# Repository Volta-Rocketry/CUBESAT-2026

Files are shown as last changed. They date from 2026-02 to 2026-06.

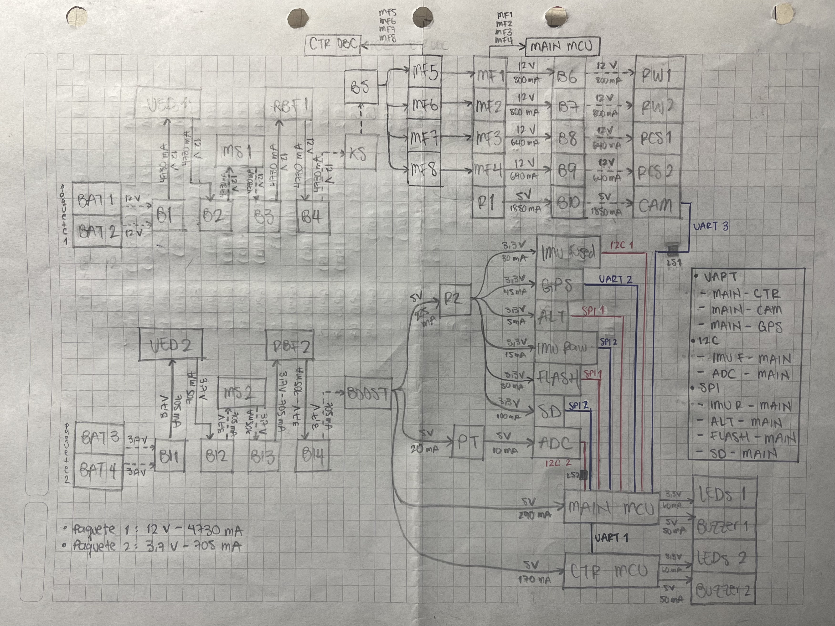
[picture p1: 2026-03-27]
ELS-ELH/Electrical Diagram.jpg

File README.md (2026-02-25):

# CUBESAT-2026
Repo for the CUBESAT - 2026

/ IMAGE OR VIDEO

## Description

Here goes the project description

## Features
Here goes the features and capabilities

## Requirements and Software
Here goes the requirements for developers to run the code

## Usage
Here goes a little guide or referral to usage manual

### IMPORTANT
Here goes important notes

## Authors and Acknowledgments
Here goes the authors and acknowledgments

## License
Here goes the license information

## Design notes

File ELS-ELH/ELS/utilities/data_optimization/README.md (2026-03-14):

## Data Strategy Analysis 
This utility simulates data throughput for a 250s mission profile at 100Hz, comparing Bitmask vs. ID-tag structures to optimize Flash saving efficiency.
## Validation and Reproducibility Steps
1. **Mission Profile:** The script uses a 250s mission profile at 100Hz.
2. **Input Verification:** The sensors used for the analysis were taken from the ones mentioned for the main OBC (The frequency was selected based on common ranges for these types of sensors, as there are no commercial references yet).
3. **Execution:** Run `python optimization_model.py`.
4. **Data Verification:** Compare the total byte count in `Data_Optimization_Analysis.xlsx` or the CSV files against the theoretical weights defined in the `dictionary_sensors` and confirm that low-frequency sensors only contribute data every X cycles, as expected in the ID-tag structure.
5. **Expected Output:** The ID-tag structure should demonstrate higher storage efficiency by omitting redundant data from lower-frequency sensors.

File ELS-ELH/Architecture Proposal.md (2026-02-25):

# ELH-ELS (Electronics Hardware and Software) Architecture Proposal

## Battery Packs Concept
In all proposed architectures, the term battery packs refers to two electrically identical sets of batteries, equal in chemistry, capacity, nominal voltage, and performance envelope. These packs are designed to be interchangeable from an electrical standpoint. However, only one pack is actively used at any given time, while the other remains available as a redundant or alternate source.

## General Elements
Across all proposed architectures, a common set of core subsystems is preserved to ensure functional consistency, comparability, and predictable system behavior. These elements are treated as architecture-invariant, meaning their role, and fundamental interaction model remain unchanged regardless of how processing, control, or power management responsibilities are distributed.

The system includes a GPS receiver used for absolute positioning, velocity estimation, and time reference. This provides global navigation data that complements inertial and barometric measurements and serves as a long-term correction source for state estimation algorithms.

Two inertial measurement units are incorporated with distinct roles. The first is an IMU with integrated sensor fusion capabilities, intended to provide a reliable, low-latency estimate of attitude and angular rates with minimal computational overhead. This fused output is primarily used for fast-loop control, initialization, and redundancy. In parallel, a second IMU dedicated exclusively to raw sensor data acquisition is included. This device provides unprocessed accelerometer, gyroscope and magnetometer measurements, enabling custom filtering, advanced state estimation, post-flight analysis, and algorithm validation independent of vendor-provided fusion.

A single barometric pressure sensor is used for altitude estimation and vertical rate computation. Its data complements inertial measurements and is especially relevant for low-frequency altitude tracking and apogee detection. The barometer is shared as a common input across estimation and logging subsystems.

For data persistence, the system integrates non-volatile flash memory to support continuous onboard data logging during flight. This storage is intended for high-reliability recording of critical sensor data, and system states. In addition, a physical SD card slot is included to allow retrieval of detailed flight data after recovery.

Finally, the system incorporates LED indicators and a buzzer to provide immediate visual and audible feedback regarding system states such as power-up, arming status, fault conditions, and mode transitions.

## Architectures
### Option 1 - Dedicated PMC and Dual OBC
This architecture is built around two identical battery packs, routed through a Power Management Controller (PMC) that acts as the sole authority over power supervision and distribution. Although the packs are electrically identical, their usage is differentiated by design: one pack is primarily associated with the actuator power domain, while the other supplies the onboard computers (OBCs). Only one pack per domain is active at a time, with selection and protection handled according to domain criticality.

The PMC, implemented on a dedicated microcontroller, continuously monitors both identical battery packs by measuring voltage, current, and optionally temperature. In addition to pack-level supervision, it monitors the electrical consumption of each actuator channel individually.

For the actuator power domain, the two identical battery packs are routed through PMC-controlled electronic power switches. The PMC firmware explicitly selects which actuator battery pack is connected to the actuator bus at any given time, and can fully disconnect or switch between packs as needed. This allows the PMC to actively choose the power source for the actuators and to isolate a pack in response to excessive current draw, detected faults, degradation, or higher-level system states.

Downstream of the selected actuator pack, each actuator channel is further gated by electronically controlled switches, also commanded by the PMC. This enables per-channel activation, isolation, and load shedding, ensuring that both pack selection and individual actuator enablement are under direct PMC control.

In contrast, the battery pack supplying the onboard computers is governed primarily by hardware supervision rather than firmware logic. Undervoltage, overcurrent, and brown-out protection are implemented using analog hardware supervisors capable of removing or restoring power independently of PMC firmware execution. The PMC passively observes and reports the state of this OBC power rail, but it does not act as the sole decision-maker. This design ensures that OBC power behavior remains deterministic, bounded, and resistant to software failure, even if the PMC firmware becomes compromised.

Above the PMC operate two onboard computers with clearly separated responsibilities.

OBC #1 (Primary Control OBC) is dedicated exclusively to running control algorithms and robust state estimation. Its design philosophy assumes that actuator power channels are available, not something it actively manages. When channels are enabled by the PMC, OBC #1 simply outputs control signals to the actuators. It does not perform power arbitration, logging, communication, or sensor preprocessing. Its operation depends on receiving validated sensor data and system status from OBC #2.

OBC #2 (Secondary / Data and Services OBC) is responsible for all sensor interfacing and data handling. It acquires raw sensor data, processes and conditions it, runs secondary or complementary state estimation algorithms, and stores data for later retrieval. It also handles non-critical system services such as data logging, Bluetooth communication with an external application. OBC #2 acts as a data provider to OBC #1, delivering sensor information and derived state estimates on demand. In this architecture, OBC #2 is also responsible for communication with the PMC, collecting power status, fault flags, and battery telemetry.

This architecture enforces strict separation: the PMC controls power, OBC #1 controls behavior, and OBC #2 manages data and interaction.

### Option 2 - Dual OBC Architecture Without PMC

Architecture 2 removes the dedicated PMC while keeping the two-OBC structure and the concept of identical battery packs. The packs still exist as separate power sources, but they are no longer routed through an intelligent power authority. Instead, battery protection is limited to passive hardware elements such as fuses, current limiters, and voltage regulators.

Without the PMC, no component has authoritative control over power distribution. Battery pack selection is hardware configured, and no actuator channels can be actively enabled or disabled at runtime based on power conditions. Power-related decisions are reduced to monitoring on pack status.

The Primary Control OBC (OBC #1) retains its focused role: running control algorithms and robust state estimation. It continues to assume that actuator power channels are available, and it outputs control signals accordingly. 

The Secondary OBC (OBC #2) monitors battery voltages and currents and continues to handle sensor processing, data storage, logging, and communication (including Bluetooth). It reports battery status and warnings to OBC #1, but it cannot directly isolate faults or remove power from loads. Communication between the two OBCs remains similar to Architecture 1, but without the PMC, fault handling becomes slower, less deterministic, and entirely software-dependent.

Compared to Architecture 1, this design reduces hardware complexity but sacrifices independent power authority and fast fault isolation.

### Option 3 - Single-OBC

Architecture 3 collapses the responsibilities of Architecture 2 into a single onboard computer. The system still uses one or two identical battery packs, but domain separation is minimal, and power protection relies almost entirely on passive hardware and basic software checks.

In this architecture, the single OBC performs control, state estimation, sensor acquisition, and basic battery monitoring within a single firmware context. Sensor data is processed locally, and only essential state estimation algorithms are executed. Non-essential services are removed: Bluetooth communication and higher-level interaction features are not included.

Battery monitoring is simplified to a reduced set of measurements, typically at lower sampling rates. There is no independent supervisory layer, no secondary data-processing unit, and no authoritative power control. Any software fault or overload directly impacts all system functions simultaneously.

This architecture prioritizes minimal hardware, fast development, and simplicity. Relative to Architectures 1 and 2, it offers the least robustness and the weakest fault isolation, but it may be acceptable for early prototypes or low-risk applications.

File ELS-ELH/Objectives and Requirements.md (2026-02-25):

# ELH-ELS (Electronics Hardware and Software) Objectives and Requirements

## Objectives
### General Objective
Develop an electronics platform to support control, power, and payload operations required for 2026 Volta´s Cubesat mission.
### Specific Objectives
1. Provide electrical power availability to enable nominal operation of all primary subsystems.
2. Support attitude determination and control activities during descent.
3. Enable system-level awareness of mission flight phases for operational decision-making.
4. Ensure system operability through defined modes, including startup, nominal operation, contingency, and safe states.
5. Enable reliable data handling, including acquisition, routing, storage, and access for onboard and ground use.
6. Enable verification and validation of system behavior through observable states and testable interfaces.

## Success Criteria
### Objective 1
- The objective is considered successful if all primary subsystems remain powered and operational throughout all defined operational modes without unintended resets or power interruptions.
### Objective 2
- The objective is considered successful if attitude state information is continuously available to the control logic throughout the descent phase without loss of estimation.
### Objective 3
- The objective is considered successful if the system correctly transitions between defined flight phases in a manner consistent with the mission timeline and external events.
- The objective is considered successful if the current flight phase is externally observable and unambiguous at all times.
### Objective 4
- The objective is considered successful if the system can enter, operate within, and exit all defined operational modes without manual intervention.
- The objective is considered successful if the system can transition to a safe or contingency mode in response to anomalous conditions.
### Objective 5
- The objective is considered successful if mission-critical data is correctly acquired, routed, and made available to onboard consumers when required.
- The objective is considered successful if stored data remains accessible and uncorrupted across operational modes and power cycles.
- The objective is considered successful if relevant data can be accessed at ground after operation
### Objective 6
- The objective is considered successful if system states, transitions, and key behaviors are externally observable through defined interfaces.
- The objective is considered successful if system behavior can be verified through repeatable tests conducted in representative operational conditions.
- The objective is considered successful if test results can be traced to specific objectives and system behaviors.

## System Requirements
- The system shall detect and record power-related anomalies that affect subsystem operation..
- The system shall provide attitude state information required for control functions during the descent phase.
- The system shall support execution of attitude control actions during descent.
- The system shall detect and report loss or degradation of attitude information.
- The system shall maintain an internal representation of the current mission flight phase.
- The system shall transition between defined flight phases based on mission events or conditions.
- The system shall expose the current flight phase as an externally observable state.
- The system shall support startup, nominal, contingency, and safe operational modes.
- The system shall transition between operational modes without manual intervention.
- The system shall maintain basic operational functionality in safe mode.
- The system shall maintain basic operational functionality in safe mode.
- The system shall store mission-critical data for later access.
- The system shall preserve data integrity across operational modes and power cycles.
- The system shall support monitoring of key system behaviors during operation.

## External and Imposed Requirements
- The system shall not include LIPO batteries
- The system shall provide data from the IMU and the Altimeter to the camera subsystem on demand
- The system shall provide functionality to two electrovalves operating at 12V with an aproximate power consumption of 7.6 W.
- The system shall provide functionality to one analog pressure transductor operating at 5V

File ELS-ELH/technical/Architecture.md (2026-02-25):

NOTE: It is missing to add a pressure sensor from the RCS system

# ELH-ELS (Electronics Hardware and Software) Architecture

## Description
The system is based on two electrically identical battery packs providing full energy redundancy, with a dedicated Power Management Controller (PMC) acting as the sole authority for power supervision and distribution, where one pack at a time is selected per domain while the other remains isolated as a hot spare; the PMC continuously monitors voltage, current and faults, actively selects which pack powers the actuator bus, and individually enables, disables, or isolates each actuator channel through electronic switches, while the power rail feeding the onboard computers is protected by independent hardware supervisors (undervoltage, overcurrent and brown-out) that guarantee deterministic behavior even in the presence of PMC firmware failures, with the PMC only monitoring this rail; above this power layer operate two onboard computers with strictly separated roles, where the MAIN OBC performs all system-level functions including sensor acquisition (GPS, fused IMU, raw IMU and barometer), state estimation, data logging to flash and SD, communications, mode management, fault handling and PMC supervision, and distributes validated state information, while the CTR OBC is dedicated exclusively to real-time control and flight dynamics, generating actuator commands based on the received state without handling power, logging or communications, resulting in a modular, fault-tolerant and safety-oriented architecture that cleanly separates electrical authority, system intelligence and control execution.

## Pin and Interface Budget
### PMC
| TYPE | ITEM | PINS | COMMENTS |
|---|---|---|---|
| OUTPUT | Pack selector | 1 | For battery selection |
| OUTPUT | Power Control CH1 (RW motor 1) | 1 | Requirement by RW|
| OUTPUT | Power Control CH2 (RW motor 2) | 1 | Requirement by RW|
| OUTPUT | Power Control CH3 (RCS Valve 1) | 1 |Requirement by RCS|
| OUTPUT | Power Control CH4 (RCS Valve 2) | 1 |Requirement by RCS|
| OUTPUT | Power Control CH5 (CAM) | 1 |Requirement by Camera Control|
| OUTPUT | Power Control CH6 (SOL) | 1 |Requirement by Solar Panel Array|
| COM | UART1 TX (MAIN OBC) | 1 | For communication with main OBC|
| COM | UART1 RX (MAIN OBC) | 1 |For communication with main OBC |
| COM | SDA I2C1 | 1 |I2C1 bus definition |
| COM | SCL I2C1 | 1 |I2C1 bus definition |
| SENSOR | CH1 Power Monitor IC | 0 | Connected to I2C1 |
| SENSOR | CH2 Power Monitor IC | 0 | Connected to I2C1 |
| SENSOR | CH3 Power Monitor IC | 0 | Connected to I2C1 |
| SENSOR | CH4 Power Monitor IC | 0 | Connected to I2C1 |
| SENSOR | CH5 Power Monitor IC | 0 | Connected to I2C1 |
| SENSOR | CH6 Power Monitor IC | 0 | Connected to I2C1 |
| SENSOR | Pack 1 Power Monitor IC | 0 | Connected to I2C1 |
| SENSOR | Pack 2 Power Monitor IC | 0 | Connected to I2C1 |
| OUTPUT | Buzzer | 1 | PWM |
| OUTPUT | LEDs | 3 | PWM |

### MAIN OBC
| TYPE | ITEM | PINS | COMMENTS |
|---|---|---|---|
| COM | UART1 TX (PMC) | 1 | For communication with PMC |
| COM | UART1 RX (PMC) | 1 | For communication with PMC |
| COM | UART2 TX (CTR OBC) | 1 | For communication with Control OBC |
| COM | UART2 RX (CTR OBC) | 1 | For communication with Control OBC |
| COM | UART3 TX (CAM) | 1 | For communication with Cameras Module |
| COM | UART3 RX (CAM) | 1 | For communication with Cameras Module |
| COM | UART4 TX (GPS) | 1 | For GPS module connection |
| COM | UART4 RX (GPS) | 1 | For GPS module connection |
| COM | UART5 TX (BT) | 1 | For BT module coneection |
| COM | UART5 RX (BT) | 1 | For BT module coneection |
| COM | SDA I2C1 | 1 | I2C1 bus definition |
| COM | SCL I2C1 | 1 | I2C1 bus definition |
| COM | SDA I2C2 | 1 | I2C2 bus definition |
| COM | SCL I2C2 | 1 | I2C2 bus definition |
| COM | SCK SPI1 | 1 | SPI1 bus definition|
| COM | MOSI SPI1 | 1 | SPI1 bus definition |
| COM | MISO SPI1 | 1 | SPI1 bus definition |
| COM | SCK SPI2 | 1 |SPI2 bus definition |
| COM | MOSI SPI2 | 1 |SPI2 bus definition |
| COM | MISO SPI2 | 1 | SPI2 bus definition|
| SENSOR | IMU 9DOF Fused | 0 | Connected to I2C1 |
| SENSOR | IMU 9DOF Raw | 0 | Connected to I2C2 |
| SENSOR | Altimeter | 0 | Connected to I2C1 |
| SENSOR | GPS | 0 | Connected to UART5 |
| SENSOR | Flash | 1 | Connected to SPI1 |
| SENSOR | SD Card | 1 | Connected to SPI2 |
| COM | Bluetooth Capability | 0 | Connected to UART |
| OUTPUT | Buzzer | 1 | Connected to PWM |
| OUTPUT | LEDs | 3 | Connected to PWM |
| OUTPUT | SOL Control Channel | 1 | |

### CTR OBC
| TYPE | ITEM | PINS | COMMENTS |
|---|---|---|---|
| COM | UART1 TX (MAIN OBC) | 1 | |
| COM | UART1 RX (MAIN OBC) | 1 | |
| OUTPUT | Control CH1 (RW motor 1) | 1 | PWM |
| OUTPUT | Control CH2 (RW motor 2) | 1 | PWM |
| OUTPUT | Control CH3 (RCS Valve 1) | 1 | PWM |
| OUTPUT | Control CH4 (RCS Valve 2) | 1 | PWM |
| OUTPUT | Control CH5 (RCS Valve 3) | 1 | PWM |
| OUTPUT | Control CH6 (RCS Valve 4) | 1 | PWM |
| OUTPUT | Buzzer | 1 | PWM |
| OUTPUT | LEDs | 3 | PWM |

### Summary
| MCU | UART | I2C | SPI | PWM  | Total Pins |
|---|---|-----|-----|---|---|
| PMC | 1 | 1 | 0 | 4 | 15 |
| MAIN OBC | 5 | 2 | 2 | 4 | 27 |
| CTR OBC  | 1 | 0 | 0 | 10 | 12 | 
---
*NOTE 1:* Main OBC shall include bluethoot capabilities \
*NOTE 2:* Control OBC shall be a control type MCU \
*NOTE 3:* Main OBC can use RTOS

## Power Budget
### PMC
| ITEM | Operating Voltage (V) | Operating Consumption (mA) | Total Power Consumption (W) | Expected Operating Time (s) | Time Justification | Total Energy (Wh) |
| --- | ---: | ---: | ---: | ---: | --- | ---: |
| MCU | 3.3 | 18 | 0.060 | 250 | Always ON (PAD, ascent, mission) | 0.00417 |
| Pack selector | 5.0 | 20 | 0.10 | 250 | Continuous EPS supervision | 0.00694 |
| Power Control CH1 (RW motor 1)  | 12.0 | 800 | 9.6 | 223 | Continuous roll stabilization post-ejection | 0.595 |
| Power Control CH2 (RW motor 2)  | 12.0 | 800 | 9.6 | 223 | Continuous roll stabilization post-ejection | 0.595 |
| Power Control CH3 (RCS Valve 1) | 12.0 | 640 | 7.7 | 22 | Intermittent roll corrections (~10% duty) | 0.0470 |
| Power Control CH4 (RCS Valve 2) | 12.0 | 640 | 7.7 | 22 | Intermittent roll corrections (~10% duty) | 0.0470 |
| Power Control CH5 (CAM) | 5.0 | 1850 | 9.25 | 250 | Explicit requirement: full mission | 0.642 |
| Power Control CH6 (SOL) | 5.0 | 200 | 1.0 | 5 | Single-shot nichrome heating | 0.00139 |
| CH1 Power Monitor IC | 3.3 | 5 | 0.017 | 250 | Continuous power monitoring | 0.00118 |
| CH2 Power Monitor IC | 3.3 | 5 | 0.017 | 250 | Continuous power monitoring | 0.00118 |
| CH3 Power Monitor IC | 3.3 | 5 | 0.017 | 250 | Continuous power monitoring | 0.00118 |
| CH4 Power Monitor IC | 3.3 | 5 | 0.017 | 250 | Continuous power monitoring | 0.00118 |
| CH5 Power Monitor IC | 3.3 | 5 | 0.017 | 250 | Continuous power monitoring | 0.00118 |
| CH6 Power Monitor IC | 3.3 | 5 | 0.017 | 250 | Continuous power monitoring | 0.00118 |
| Pack 1 Power Monitor IC | 3.3 | 5 | 0.017 | 250 | Continuous pack monitoring | 0.00118 |
| Pack 2 Power Monitor IC | 3.3 | 5 | 0.017 | 250 | Continuous pack monitoring | 0.00118 |
| Buzzer | 5.0 | 50 | 0.25 | 20 | Distributed status beeps | 0.00139 |
| LEDs (3×) | 3.3 | 60 | 0.20 | 250 | Continuous status indication | 0.0139 |

### Main OBC
| ITEM | Operating Voltage (V) | Operating Consumption (mA) | Total Power Consumption (W) | Expected Operating Time (s) | Time Justification | Total Energy (Wh) |
| --- | ---: | ---: | ---: | ---: | --- | ---: |
| MCU | 3.3 | 180 | 0.60 | 250 | Always ON | 0.0417 |
| IMU 9DOF Fused | 3.3 | 30 | 0.10 | 223 | Only useful post-ejection | 0.00619 |
| IMU 9DOF Raw | 3.3 | 15 | 0.05 | 250 | Launch detection + backup | 0.00347 |
| Altimeter | 3.3 | 5 | 0.017 | 250 | Launch, apogee, descent awareness | 0.00118 |
| GPS | 3.3 | 45 | 0.15 | 223 | Post-ejection navigation | 0.00929 |
| Flash | 3.3 | 30 | 0.10 | 250 | Primary flight data logger | 0.00694 |
| SD Card (active) | 3.3 | 100 | 0.33 | 10 | Landing-only data dump | 0.00092 |
| Bluetooth Capability | 3.3 | 40 | 0.13 | 0 | Disabled in flight | 0.00000 |
| Buzzer | 5.0 | 50 | 0.25 | 20 | Distributed status beeps | 0.00139 |
| LEDs (3×) | 3.3 | 60 | 0.20 | 250 | Continuous status indication | 0.0139 |

### CTR OBC
| ITEM | Operating Voltage (V) | Operating Consumption (mA) | Total Power Consumption (W) | Expected Operating Time (s) | Time Justification | Total Energy (Wh) |
| --- | ---: | ---: | ---: | ---: | --- | ---: |
| MCU | 3.3 | 80 | 0.26 | 223 | Control active only post-ejection | 0.0161 |
| Buzzer | 5.0 | 50 | 0.25 | 20 | Distributed status beeps | 0.00139 |
| LEDs (3×) | 3.3 | 60 | 0.20 | 223 | Active during CubeSat mission | 0.0124 |

### Raw Summary
| CATEGORY | INCLUDED ELEMENTS | Total Energy (Wh) | COMMENT |
| --- | --- | ---: | --- |
| Actuation & Payload Channels | RW motors (×2), RCS valves (×2), Camera channel, SOL nichrome channel | ≈ 1.93 Wh | Dominant energy driver; camera + RW are primary contributors |
| Computation, Sensors & ICs | All MCUs (PMC, Main OBC, CTR OBC), IMUs, GPS, Altimeter, Flash, SD , Power Monitor ICs, LEDs, Buzzers | ≈ 0.15 Wh | Control, sensing, monitoring, and housekeeping |

### Final decision
The total energy budget is divided into two independent battery domains with margins applied according to the dominant risks of each domain. The first domain, corresponding to actuation and payload channels (reaction wheels, RCS valves, camera channel, and the single-shot nichrome deployment channel), is active only during the mission phase after CubeSat ejection and is therefore dominated by short-duration, high-power operation. For this domain, the raw mission energy of approximately 1.93 Wh is increased by an allowance for EPS conduction and switching losses (≈10%), followed by a DC/DC conversion and wiring efficiency margin of 15%, and a system-level design margin of 30% to cover uncertainty in duty cycles and actuator usage. These combined margins result in a required battery capacity of approximately 3.0 Wh for the actuation and payload battery.

The second domain supplies all computation, sensing, and housekeeping functions, including all MCUs, sensors, memory devices, power monitor ICs, LEDs, and buzzers, and is dominated by long-duration low-power operation during the PAD phase. For this domain, the base energy consists of approximately 0.15 Wh during the mission plus about 1.5 Wh consumed during a three-hour PAD period, with an additional small allowance for EPS quiescent currents and leakage. Margins applied to this domain include a 15% margin for DC/DC conversion and distribution losses, a 20% derating to account for temperature effects and battery aging, and a 30% design margin to cover variability in PAD duration and operational modes. After applying these margins, the resulting required battery capacity for the computation and sensor domain is approximately 3.2 Wh.

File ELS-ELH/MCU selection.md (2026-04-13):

| Features | ESP32-S3 | ESP32-WROOM | ESP32-C3 | ESP32-C6 | ESP32-H2 |
|---|---|---|---|---|---|
| Clock Frequency (MHz) | 240 | 240 | 160 | 160 | 96 |
| SRAM (KB) | 512 | 520 | 400 | 512 | 320 |
| Flash (MB) | 16 | 4 | 4 | 8 | 4 |
| GPIO Quantity | 45 | 34 | 22 | 30 | 28 |
| Pin Restriction | 0 | 4 | 0 | 0 | 0 |
| Analog Output | 0 | 2 | 0 | 0 | 0 |
| Bluetooth | BLE | BLE & Classic | BLE | BLE | BLE |
| Wi-Fi | Yes | Yes | Yes | Yes | No |

The ESP32-WROOM is selected because it meets the requirement of Bluetooth Classic, in addition to BLE, unlike the ESP32-S3, ESP32-C3, ESP32-C6, and ESP32-H2, which only support BLE. 

In terms of performance, the ESP32-WROOM offers a good balance, with a clock frequency of 240 MHz and 520 KB of SRAM. Although the ESP32-S3 stands out for having more Flash memory (16 MB) and more GPIOs, it does not meet the Bluetooth Classic requirement. 

Also, the C3, C6, and H2 models have lower processing capabilities and also lack Bluetooth Classic, so they are discarded. 

Therefore, the ESP32-WROOM is the most suitable choice for the project, providing the necessary Bluetooth functionality while maintaining a strong performance profile.

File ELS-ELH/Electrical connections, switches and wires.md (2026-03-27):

# Electrical Connections, Switches, and Wires

## Purpose of this Document
This document defines part of the proposed final structure system for the CUBESAT for 2026 IREC competition, focusing on electronic safety equipment.

## Electronics Safety Equipment
A system with three types of switches is proposed for the electronic structure of the CUBESAT for reasons of safety, versatility, and with the aim of preventing discharges or long system operating times. However, some guidelines should be taken into account.

## Electrical Schematic Diagram 
The diagram is in this same folder in JPG format.

Electrical Schematic Diagram

### Meaning of each abbreviation
| Abbreviation | Meaning | 
| :--- | :--- |
| BAT1 | Battery Pack 1 | 
| BAT2 | Battery Pack 1 | 
| BAT3 | Battery Pack 2 | 
| BAT4 | Battery Pack 2 | 
| UED1 | Unknown Energy Distributor 1 | 
| UED2 | Unknown Energy Distributor 2 | 
| MS1 | Master Switch 1 | 
| MS2 | Master Switch 2 | 
| RBF1 | Remove Before Fly 1 | 
| RBF2 | Remove Before Fly 2 | 
| KS | Kill Switch | 
| BOOST | Booster | 
| R1 | Regulator 1 | 
| R2 | Regulator 2 | 
| CAM | Camera | 
| PT | Pressure Transducer |
| RW(1,2) | Reaction Wheels |
| RCS(1,2) | Electroválvulas |
| LS1 | Level Shifter 1 | 
| LS2 | Level Shifter 2 | 
| MF(1-8) | Mosfets | 
| B(1-14) | Borneras |

### Master Switch
This switch is used as redundancy for the rbf switch. If it were not there, the system's power supply would depend on it (RBF), which is very volatile and would pose many risks. It (MASTER) is used for security functions.

### RBF Switch
This switch consists of a removable pin that is inserted and removed through a hole in the fuselage when the CUBESAT is assembled inside the launch vehicle. The pin is inserted, the master switch is turned on, and then the pin is removed from the RBF to energize the computing and sensor area.

### Kill Switch
These switches are located in the actuator area and allow power to pass only when the CUBESAT is ejected from the launch vehicle.

### MOSFETS
These are electronic switches located in each actuator, there are two MOSFETs per actuator, both connected in series, for a total of eight. Each “column” has four, and each will be controlled by a different OBC: the main OBC will manage the power supply, and the control OBC will manage the actuators' activation.

## Pin Budget (Preliminar)
### 1. MAIN OBC: ESP32-S3 (DevKitC-1)

| Categoría | Ítem | Pin (GPIO) |
| :--- | :--- | :--- |
| COM | UART1 TX (CTR OBC) | 43 | 
| COM | UART1 RX (CTR OBC) | 44 | 
| COM | UART2 TX (CAM) | 15 | 
| COM | UART2 RX (CAM) | 16 |
| COM | UART3 TX (GPS) | 17 | 
| COM | UART3 RX (GPS) | 18 |
| I2C1 | SDA (IMU Fused) | 4 | 
| I2C1 | SCL (IMU Fused) | 5 | 
| I2C2 | SDA (ADC) | 6 | 
| I2C2 | SCL (ADC) | 7 | 
| SPI1 | SCK (Flash/ALT) | 12 | 
| SPI1 | MOSI (Flash/ALT) | 11 | 
| SPI1 | MISO (Flash/ALT) | 13 |
| CS1 | CS (Flash) | 10 | 
| CS1 | CS (ALT) | 14 | 
| SPI2 | SCK (IMU Raw/SD) | 36 | 
| SPI2 | MOSI (IMU Raw/SD) | 35 | 
| SPI2 | MISO (IMU Raw/SD) | 37 |
| CS2 | CS (IMU Raw) | 47 | 
| CS2 | CS (SD) | 48 | 
| OUTPUT | Buzzer | 2 | 
| OUTPUT | LEDs x3 | 38, 39, 40 | 
| OUTPUT | MOSFET 1 (RW1) | 21 | 
| OUTPUT | MOSFET 2 (RW2) | 41 | 
| OUTPUT | MOSFET 3 (RCS1) | 42 | 
| OUTPUT | MOSFET 4 (RCS2) | 9 | 

### 2. CTR OBC: TEENSY 4.1

| Categoría | Ítem | Pin |
| :--- | :--- | :--- |
| COM | UART1 TX (MAIN OBC) | 1 | 
| COM | UART1 RX (MAIN OBC) | 0 | 
| OUTPUT | Buzzer | 6 | 
| OUTPUT | LEDs x3 | 9, 10, 11 | 
| OUTPUT | MOSFET 5 (RW1) | 2 | 
| OUTPUT | MOSFET 6 (RW2) | 3 | 
| OUTPUT | MOSFET 7 (RCS1) | 4 | 
| OUTPUT | MOSFET 8 (RCS2) | 5 |

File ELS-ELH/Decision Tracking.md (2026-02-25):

# ELH-ELS (Electronics Hardware and Software) Decision Tracking

## Objective and Scope
The purpose of this document is to formally capture, justify, and maintain traceability of all major technical and architectural decisions related to the ELH-ELS (Electronics Hardware and Software) system.

The scope includes, but is not limited to:

- Hardware architecture and component selection
- Firmware and software architecture
- Interfaces, protocols, and data flows
- Safety, redundancy, and fault-handling strategies
- Power, performance, and reliability trade-offs

### Note
All prices are quoted in USD and, unless otherwise specified, electronic component pricing is sourced from the Mouser Electronics website.

## Decisions
### Architecture
Based on team reviews, CubeSat standards, and system-level requirements, Architecture #1 (PMC with dual OBC) has been selected as the baseline.

This architecture provides the highest level of reliability, fault tolerance, and compliance with mission requirements. The use of a Power Management Controller (PMC) combined with dual On-Board Computers (OBCs) enables a modular, redundant, and safety-oriented design, ensuring:

- Robust fault detection, isolation, and recovery (FDIR)
- Controlled power distribution and system-level supervision
- Redundant command and data handling
- Graceful degradation in case of subsystem failure

### Component Selection - Power
#### Load Switches
Three architectures were evaluated for controlling and protecting the CubeSat power distribution rails: (1) discrete MOSFET switches driven directly by the MCU, (2) integrated eFuse / hot-swap power switches, and (3) mechanical relays. A discrete MOSFET approach provides basic on/off capability but requires additional circuitry for inrush control, short-circuit protection, reverse-current blocking, and thermal protection, making it highly layout-dependent and sensitive to EMI and PCB parasitics. Mechanical relays, while simple to control, are unsuitable due to vibration sensitivity, arcing, slow response time, and limited lifetime. Integrated eFuses combine a high-side MOSFET with programmable current limiting, soft-start, short-circuit and thermal protection, reverse-current blocking, and fault reporting in a single device, requiring only minimal external components and a simple MCU interface. This architecture provides the highest level of electrical protection with the lowest implementation complexity and risk, making the eFuse-based solution the most robust and appropriate choice for the CubeSat Power Management Computer.

The devices listed in the following table represent the full spectrum of integrated eFuse solutions available for protected power distribution, spanning from low-power to very high-current applications. These parts were selected for comparison because they share the same architectural model, integrated back-to-back MOSFETs, programmable current limiting, inrush control, reverse-current blocking, thermal protection, and MCU-friendly EN/FLT/PGOOD interfaces, while differing mainly in voltage range, current capability, and $R_{DS_{on}}$. 

Lower-current parts such as the TPS25940 and TPS25946 are well suited for CubeSat subsystem rails, offering sufficient current capacity with lower cost and simpler PCB thermal requirements. Higher-current devices (TPS25983 and TPS25984x) support much larger loads but require larger packages, heavier copper, wider pours, and more thermal management, significantly increasing PCB complexity, mass, and layout risk. 

| Part | Voltage  | Current  | Good For | Price (1/10/25)|
| --- | --- | --- | --- |----|
| **TPS25940** | 2.7–18 V | ~0.6–5 A | Base solution for low-power CubeSat rails | 2.75/2.02/1.85|
| **TPS25946** | 2.7–23 V | ~0.5–6 A | Higher voltage & lower R<sub>ds(on)</sub> | 1.43/1.04/0.95|
| **TPS25983** | 2.7–26 V | ~2–20 A  | Mid-high power rails |3.75/2.84/2.61|
| **TPS25984x** | 4.5–16 V | ~10–55 A | Heavy power distribution |8.21/5.74/5.47|

**NOTE: DECISION FROM THIS OPTION WILL TAKE PLACE AFTER THE POWER REQUIREMNTS PER CHANEL HAVE BEEN RECIEVED**

#### Power Monitor ICs
There are three viable approaches to measure power consumption in a system: (1) measuring voltage and current separately using analog dividers and shunt resistors connected to the MCU ADC, which requires external amplifiers, careful filtering, and calibration; (2) measuring only current with a shunt plus an external current-sense amplifier and then digitizing it with the ADC; or (3) using integrated high-side power monitor ICs such as the INA28x family, which include a precision amplifier, ADC, and digital interface in a single device. 

While the first two options are feasible, they introduce significant analog complexity, noise sensitivity, and calibration burden. In contrast, INA-class power monitors provide accurate high-side current, bus voltage, and power measurements with minimal external components, making them the most robust, scalable, and low-risk solution for multi-rail power telemetry and protection in a flight-critical or high-reliability power system.

The devices listed in the following table were selected for high-side current and voltage monitoring of the CubeSat power rails, balancing accuracy, bus voltage range, and integration features. The INA226 operates over 0–36 V with a 16-bit ADC and ~0.1% accuracy, making it a reliable industry-standard choice for general-purpose telemetry. The INA238 extends the bus voltage range to 0–85 V with improved accuracy (~0.05%) and a radiation-tolerant design, offering heritage suitable for aerospace applications. The MAX34417 supports 0–36 V, 16-bit resolution, and includes built-in alert functionality and filtering, simplifying system monitoring and fault detection. These devices were chosen over older alternatives such as the INA219 because they provide higher precision, true high-side sensing, alerting, and better long-term stability, which are critical for accurate measurement of multiple power rails in a CubeSat environment.

| Part | Bus Voltage | ADC | Accuracy | Addressing | Notes | Price (1/10/25)|
| --- | --- | --- | --- | --- | --- | --|
| **INA226** | 0–36 V | 16-bit | ~0.1% | 16 addr | Industry workhorse | 3.81/2.88/2.65
| **INA238** | 0–85 V | 16-bit | ~0.05% | 16 addr | Radiation-tolerant heritage | 3.17/2.38/2.18
| **MAX34417** | 0–36 V | 16-bit | ~0.1% | 8 addr | Built-in alert + filters | 15.26/11.60/11.12

**NOTE: DECISION FROM THIS OPTION WILL TAKE PLACE AFTER THE POWER REQUIREMNTS PER CHANEL HAVE BEEN RECIEVED**

#### Battery pack switchover alternatives
For providing a single output from two battery packs, three approaches were considered: (1) simple diodes for OR-ing, (2) MCU-controlled MOSFET switches, and (3) ideal-diode OR-ing controllers with external MOSFETs. Simple diodes are electrically safe but introduce significant voltage drop and wasted energy, which reduces usable battery capacity and efficiency. MCU-controlled switches offer apparent flexibility but carry high risk of cross-conduction, brownouts, and failure in case of firmware errors, making them unsuitable for critical power paths. Ideal-diode OR-ing controllers combine automatic source selection, low forward voltage drop, and inherent reverse-current blocking using external MOSFETs, providing seamless switchover without firmware dependency and minimal losses. This architecture achieves the lowest practical complexity while maintaining safety and efficiency, making the ideal-diode OR-ing the most robust and appropriate solution for CubeSat battery pack management.

The ICs listed in the following table were selected as suitable solutions for automatic battery pack switchover based on voltage range, efficiency, and integration features. The LM74700D-Q1 supports a wide voltage range (~3.2–65 V) with very low forward voltage drop, making it ideal for robust, low-loss selection across a broad set of battery chemistries and voltages. The LTC4412 provides automotive-grade ideal-diode control for 2.5–28 V systems, offering proven reliability, low quiescent current, and seamless switchover, suitable for standard CubeSat Li-ion packs. The MAX5079 operates up to 13.2 V and includes built-in ORing logic and status detection, simplifying system monitoring and reducing external components. These devices were chosen over discrete MOSFET logic or passive diodes because they ensure safe, low-loss, and automatic selection without firmware dependency, while minimizing PCB complexity and design risk.

| IC | Best for battery packs up to… | Key benefit | Price (1/10/25)|
| --- | --- | --- | ---|
| **LM74700D-Q1** | ~3.2 – 65 V | Very low loss, wide voltage range | 2.41/1.79/1.64
| **LTC4412** | ~2.5 – 28 V | Automotive-class ideal diode control | 15.23/11.95/11.46
| **MAX5079** | ~2.75 – 13.2 V | Built-in detection and ORing logic | 11.32/8.86/8.73

**NOTE: DECISION FROM THIS OPTION WILL TAKE PLACE AFTER THE POWER REQUIREMNTS PER CHANEL HAVE BEEN RECIEVED**

#### Kill switches

### Component Selection - OBCs
#### PMC - MCU 

#### Main OBC - MCU

#### Main OBC - 9DOF IMU Fused

#### Main OBC - 9DOF IMU Raw

#### Main OBC - Altimeter

#### Main OBC - GPS

#### Main OBC - Flash Module

#### Main OBC - Bluethoot Module

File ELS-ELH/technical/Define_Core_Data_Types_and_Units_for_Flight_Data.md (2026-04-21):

# Objective
In this part, the data and their physical units are defined, enabling consistent information exchange among the participants. This avoids variable discrepancies and interpretation errors, regardless of the hardware. Additionally, all sensors will use the exact units established in this document.
# Data Standards and Physical Units
* **Acceleration:** Meters per second squared ($m/s^2$). Variable: `accel`
  Type: `float`
* **Linear Velocity:** Meters per second ($m/s$). Variable: `linVel`
  Type: `float`
* **Angular Velocity:** Radians per second ($rad/s$). Variable: `angVel` Type: `float`
* **Magnetometer:** microteslas ($\mu T$). Variable: `mag` Type: `float`
* **Pressure:** Pascals ($Pa$). Variable: `pressure` Type: `float`
* **Altitude:** Meters ($m$). Variable: `altitude` Type: `float`
* **Temperature:** Degrees Celsius ($^\circ C$). Variable: `temp` Type: `float`
* **Humidity:** Percentage (%). Variable: `humidity` Type: `float`
* **Time:** Miliseconds ($ms$) since system startup. Variable: `timestamp` Type: `uint32_t`
* **Speed** Meters per second ($m/s$). Variable: `speed` Type: `float`

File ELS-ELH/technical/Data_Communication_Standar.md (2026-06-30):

# Data Communication Standar
---
## General

Before each packet, two separate bytes [0xAA 0x55] (uint8_t) will be sent to identify its arrival.

Each packet will have a designated ID (uint8_t) at the beginning, followed by a set packet length (uint8_t) to confirm its termination, and a CRC (uint16_t) at the end to verify the packet's integrity upon receipt.

The length_of_package variable indicates the payload length (the exact number of bytes containing the data, excluding the Sync bytes, ID, Length byte, and CRC).

All multi-byte variables shall be transmitted in Little-Endian byte order.

---

## ID Package Assignment

* ID_CTR_TP: 0X10
* ID_CAM_TP: 0X11
* ID_FGH_SP: 0X20
* ID_INIT_CMD: 0XF0

---

## Flight Data Packages

* **control_telemetry_package (CTR_TP):** package sent to the control algorithm

    * **Frequency:** 100 Hz
    * **Weight:** 59 Bytes
    * **Content:** 

        | VARIABLE | TYPE | UNIT |
        | :--- | :---: | :--- |
        | 0xAA | uint8_t | N/A |
        | 0x55 | uint8_t | N/A |
        | ID_CTR_TP | uint8_t | N/A |
        | length_of_package | uint8_t | byte |
        | timestamp | uint32_t | ms |
        | altitude | float32 | m |
        | vertical_velocity | float32 | m/s |
        | ax, ay, az | float32 | m/s^2 |
        | gx, gy, gz | float32 | rad/s |
        | qw, qx, qy, qz | float32 | N/A |
        | flight_state | uint8_t | N/A |
        | CRC-16-CCITT | uint16_t | N/A |

* **camera_telemetry_package (CAM_TP):** package sent to the camera algorithm

    * **Frequency:** 100 Hz
    * **Weight:** 34 Bytes
    * **Content:** 

        | VARIABLE | TYPE | UNIT |
        | :--- | :---: | :--- |
        | 0xAA | uint8_t | N/A |
        | 0x55 | uint8_t | N/A |
        | ID_CAM_TP | uint8_t | N/A |
        | length_of_package | uint8_t | byte |
        | timestamp | uint32_t | ms |
        | ax, ay, az | float32 | m/s^2 |
        | gx, gy, gz | float32 | rad/s |
        | CRC-16-CCITT | uint16_t | N/A |

* **flight_state_package (FGH_SP):** package containing flight status

    * **Frequency:** N/A
    * **Weight:** 15 Bytes
    * **Content:** 

        | VARIABLE | TYPE | UNIT |
        | :--- | :---: | :--- |
        | 0xAA | uint8_t | N/A |
        | 0x55 | uint8_t | N/A |
        | ID_FGH_SP | uint8_t | N/A |
        | length_of_package | uint8_t | byte |
        | timestamp | uint32_t | ms |
        | altitude | float32 | m |
        | flight_state | uint8_t | N/A |
        | CRC-16-CCITT | uint16_t | N/A |

---

## Initialize Communications Packages

* **package_init_from_Main:** package sent from main OBC to verify communications, contains the receiver ID

    * **Frequency:** N/A
    * **Weight:** 7 Bytes
    * **Content:** 

        | VARIABLE | TYPE | UNIT |
        | :--- | :---: | :--- |
        | 0xAA | uint8_t | N/A |
        | 0x55 | uint8_t | N/A |
        | ID_INIT_CMD | uint8_t | N/A |
        | length_of_package | uint8_t | byte |
        | ID_CAM_TP / ID_CTR_TP | uint8_t | N/A |
        | CRC-16-CCITT | uint16_t | N/A |

* **package_init_to_Main:** package sent from main OBC to verify communications, contains the transmitter ID

    * **Frequency:** N/A
    * **Weight:** 7 Bytes
    * **Content:** 

        | VARIABLE | TYPE | UNIT |
        | :--- | :---: | :--- |
        | 0xAA | uint8_t | N/A |
        | 0x55 | uint8_t | N/A |
        | ID_INIT_CMD | uint8_t | N/A |
        | length_of_package | uint8_t | byte |
        | ID_CAM_TP / ID_CTR_TP | uint8_t | N/A |
        | CRC-16-CCITT | uint16_t | N/A |

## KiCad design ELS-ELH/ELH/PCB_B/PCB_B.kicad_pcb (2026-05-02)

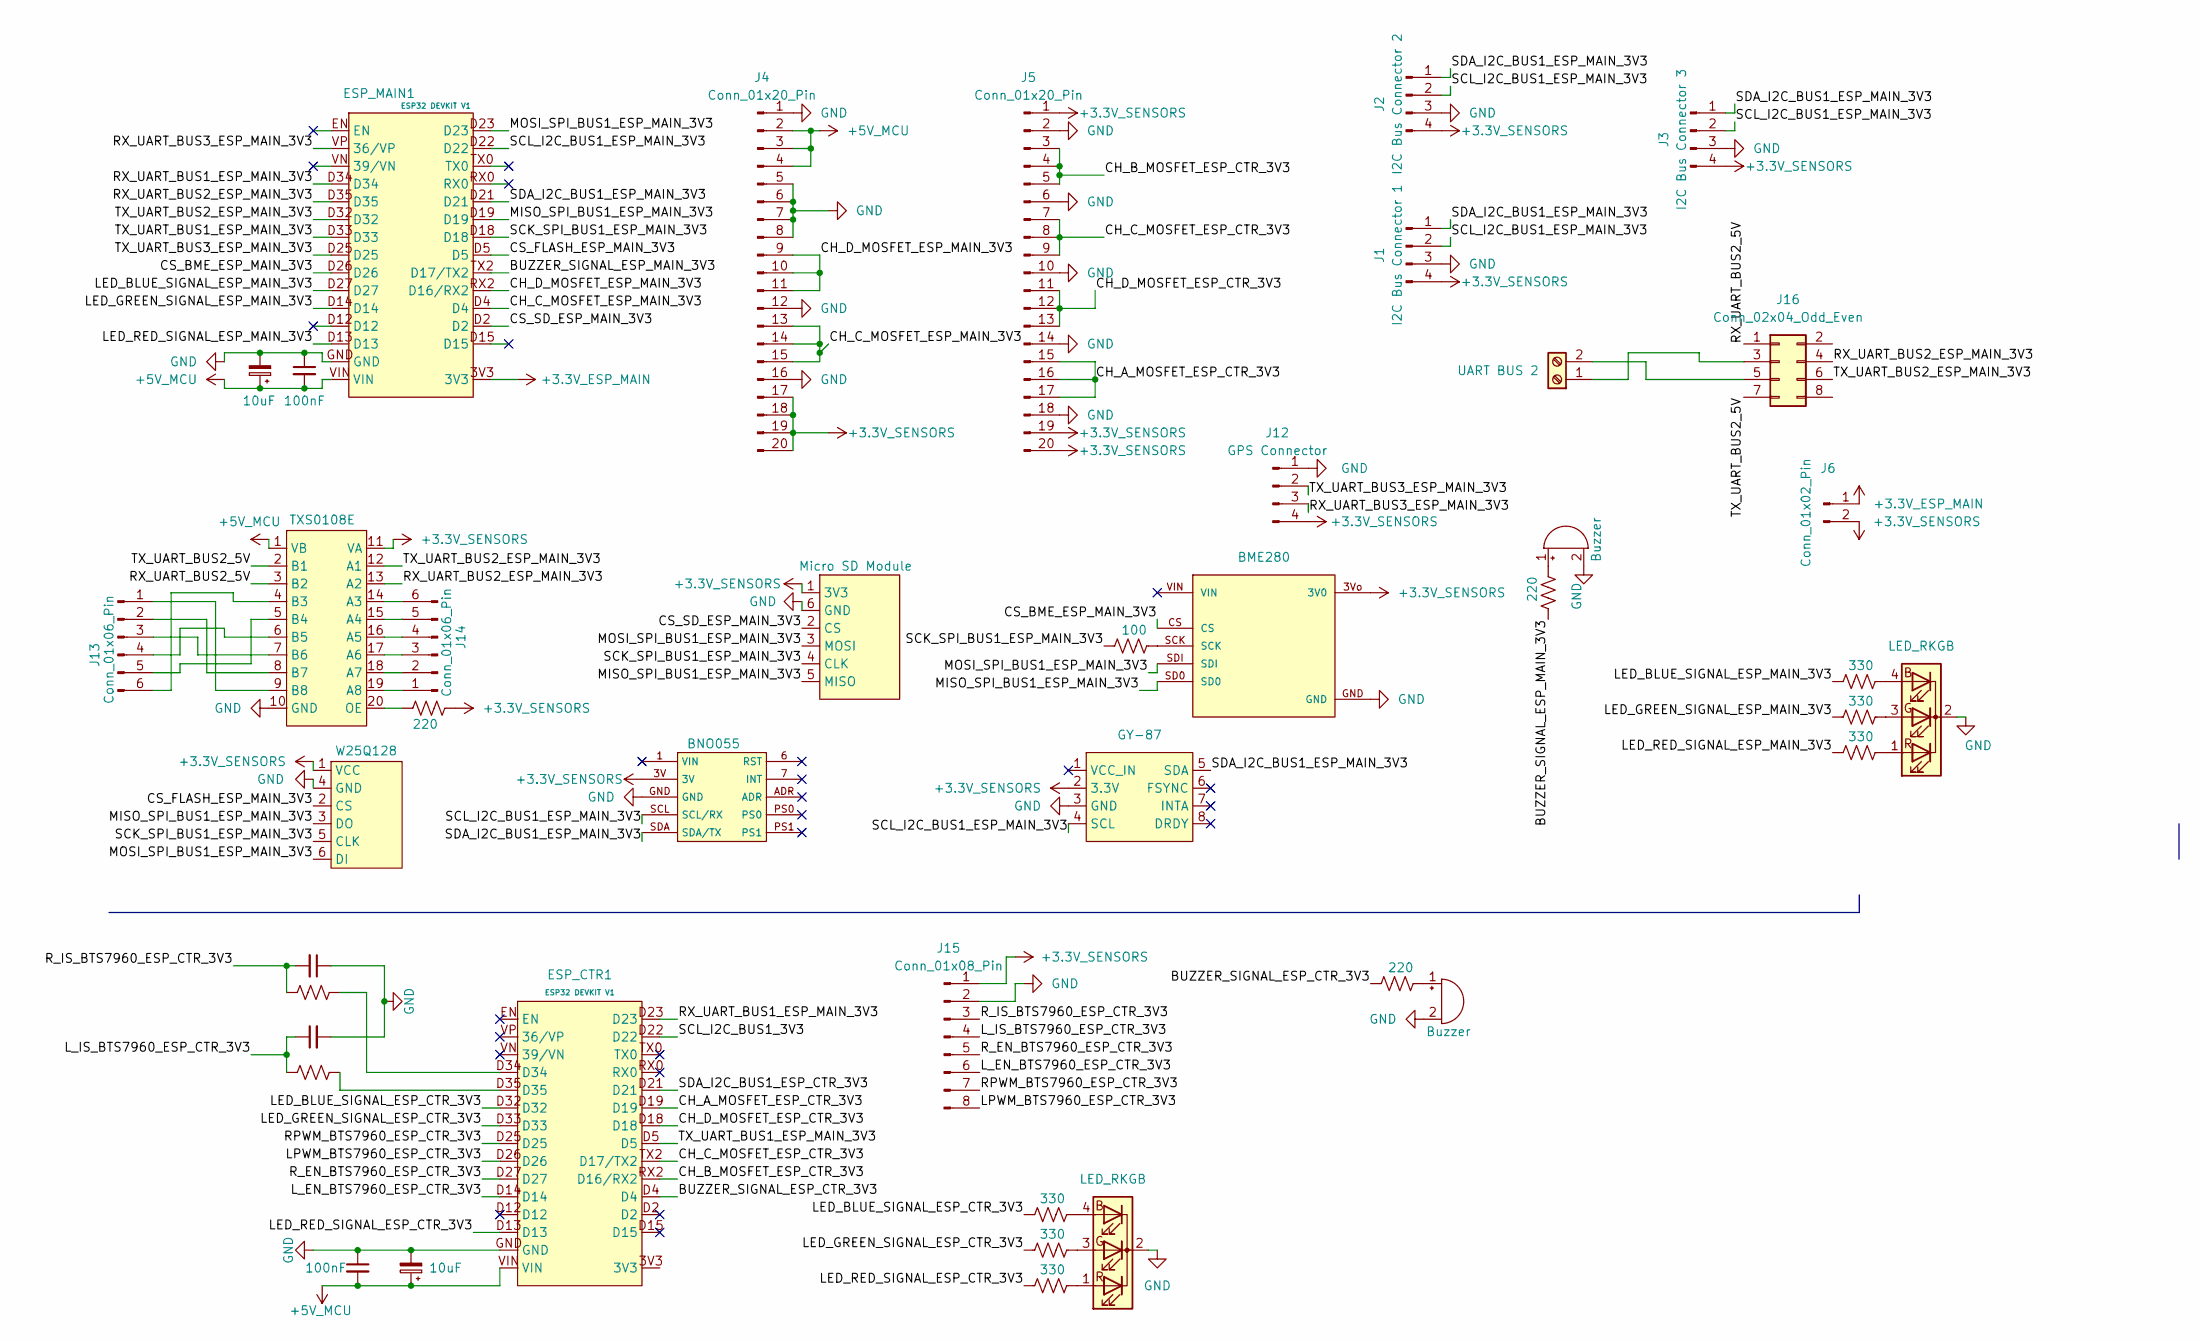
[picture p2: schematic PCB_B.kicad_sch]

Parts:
BME1: BME280
BZ1, BZ2: Buzzer
Bornera1: UART BUS 2
C1, C6: 10uF
C2, C5: 100nF
C3, C4: ???
Converter1: TXS0108E
D1, D2: LED_RKGB
ESP_CTR1: ESP32 DEVKIT V1
ESP_MAIN1: ESP32 DEVKIT V1
IMU1: BNO055
J1: I2C Bus Connector 1
J2: I2C Bus Connector 2
J3: I2C Bus Connector 3
J4, J5: Conn_01x20_Pin
J6: Conn_01x02_Pin; PinHeader_1x02_P2.54mm_Vertical
J12: GPS Connector
J13, J14: Conn_01x06_Pin
J15: Conn_01x08_Pin
J16: Conn_02x04_Odd_Even; PinHeader_2x04_P2.54mm_Vertical
R1, R3, R4, R10, R11, R12: 330
R2, R6, R7: 220
R5: 100
R8, R9: ???
SD_Adapter1: Micro SD Module; MicroSD Module
U1: GY-87
W25QXX1: W25Q128

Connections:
+3.3V_ESP_MAIN: ESP_MAIN1.3V3, J6.1
+3.3V_SENSORS: BME1.3Vo (3V0), Converter1.11 (VA), IMU1.3V, J1.4, J2.4, J3.4, J4.17, J4.18, J4.19, J4.20, J5.1, J5.19, J5.20, J6.2, J12.4, J15.1, R6.1, SD_Adapter1.1 (3V3), U1.2 (3.3V), W25QXX1.1 (VCC)
+5V_MCU: C1.1, C2.2, C5.2, C6.1, Converter1.1 (VB), ESP_CTR1.VIN, ESP_MAIN1.VIN, J4.2, J4.3, J4.4
/BUZZER_SIGNAL_ESP_CTR_3V3: ESP_CTR1.D4, R7.1
/BUZZER_SIGNAL_ESP_MAIN_3V3: ESP_MAIN1.TX2 (D17/TX2), R2.1
/CH_A_MOSFET_ESP_CTR_3V3: ESP_CTR1.D19, J5.15, J5.16, J5.17
/CH_B_MOSFET_ESP_CTR_3V3: ESP_CTR1.RX2 (D16/RX2), J5.3, J5.4, J5.5
/CH_C_MOSFET_ESP_CTR_3V3: ESP_CTR1.TX2 (D17/TX2), J5.7, J5.8, J5.9
/CH_C_MOSFET_ESP_MAIN_3V3: ESP_MAIN1.D4, J4.13, J4.14, J4.15
/CH_D_MOSFET_ESP_CTR_3V3: ESP_CTR1.D18, J5.11, J5.12, J5.13
/CH_D_MOSFET_ESP_MAIN_3V3: ESP_MAIN1.RX2 (D16/RX2), J4.9, J4.10, J4.11
/CS_BME_ESP_MAIN_3V3: BME1.CS, ESP_MAIN1.D26
/CS_FLASH_ESP_MAIN_3V3: ESP_MAIN1.D5, W25QXX1.2 (CS)
/CS_SD_ESP_MAIN_3V3: ESP_MAIN1.D2, SD_Adapter1.2 (CS)
/LED_BLUE_SIGNAL_ESP_CTR_3V3: ESP_CTR1.D32, R10.2
/LED_BLUE_SIGNAL_ESP_MAIN_3V3: ESP_MAIN1.D27, R1.2
/LED_GREEN_SIGNAL_ESP_CTR_3V3: ESP_CTR1.D33, R11.2
/LED_GREEN_SIGNAL_ESP_MAIN_3V3: ESP_MAIN1.D14, R3.2
/LED_RED_SIGNAL_ESP_CTR_3V3: ESP_CTR1.D13, R12.2
/LED_RED_SIGNAL_ESP_MAIN_3V3: ESP_MAIN1.D13, R4.2
/LPWM_BTS7960_ESP_CTR_3V3: ESP_CTR1.D26, J15.8
/L_EN_BTS7960_ESP_CTR_3V3: ESP_CTR1.D14, J15.6
/L_IS_BTS7960_ESP_CTR_3V3: C4.1, J15.4, R9.1
/MISO_SPI_BUS1_ESP_MAIN_3V3: BME1.SD0, ESP_MAIN1.D19, SD_Adapter1.5 (MISO), W25QXX1.3 (DO)
/MOSI_SPI_BUS1_ESP_MAIN_3V3: BME1.SDI, ESP_MAIN1.D23, SD_Adapter1.3 (MOSI), W25QXX1.6 (DI)
/RPWM_BTS7960_ESP_CTR_3V3: ESP_CTR1.D25, J15.7
/RX_UART_BUS1_ESP_MAIN_3V3: ESP_CTR1.D23, ESP_MAIN1.D34
/RX_UART_BUS2_5V: Converter1.3 (B2), J16.1
/RX_UART_BUS2_ESP_MAIN_3V3: Converter1.13 (A2), ESP_MAIN1.D35, J16.4
/RX_UART_BUS3_ESP_MAIN_3V3: ESP_MAIN1.VP (36/VP), J12.3
/R_EN_BTS7960_ESP_CTR_3V3: ESP_CTR1.D27, J15.5
/R_IS_BTS7960_ESP_CTR_3V3: C3.2, J15.3, R8.1
/SCK_SPI_BUS1_ESP_MAIN_3V3: ESP_MAIN1.D18, R5.1, SD_Adapter1.4 (CLK), W25QXX1.5 (CLK)
/SCL_I2C_BUS1_3V3: ESP_CTR1.D22
/SCL_I2C_BUS1_ESP_MAIN_3V3: ESP_MAIN1.D22, IMU1.SCL (SCL/RX), J1.2, J2.2, J3.2, U1.4 (SCL)
/SDA_I2C_BUS1_ESP_CTR_3V3: ESP_CTR1.D21
/SDA_I2C_BUS1_ESP_MAIN_3V3: ESP_MAIN1.D21, IMU1.SDA (SDA/TX), J1.1, J2.1, J3.1, U1.5 (SDA)
/TX_UART_BUS1_ESP_MAIN_3V3: ESP_CTR1.D5, ESP_MAIN1.D33
/TX_UART_BUS2_5V: Converter1.2 (B1), J16.7
/TX_UART_BUS2_ESP_MAIN_3V3: Converter1.12 (A1), ESP_MAIN1.D32, J16.6
/TX_UART_BUS3_ESP_MAIN_3V3: ESP_MAIN1.D25, J12.2
GND: BME1.GND, BZ1.2 (-), BZ2.2 (-), C1.2, C2.1, C3.1, C4.2, C5.1, C6.2, Converter1.10 (GND), D1.2 (K), D2.2 (K), ESP_CTR1.GND, ESP_MAIN1.GND, IMU1.GND, J1.3, J2.3, J3.3, J4.1, J4.5, J4.6, J4.7, J4.8, J4.12, J4.16, J5.2, J5.6, J5.10, J5.14, J5.18, J12.1, J15.2, SD_Adapter1.6 (GND), U1.3 (GND), W25QXX1.4 (GND)
unnamed: BME1.SCK, R5.2
unnamed: BZ1.1 (+), R2.2
unnamed: BZ2.1 (+), R7.2
unnamed: Bornera1.1, J16.3
unnamed: Bornera1.2, J16.5
unnamed: Converter1.14 (A3), J14.6
unnamed: Converter1.15 (A4), J14.5
unnamed: Converter1.16 (A5), J14.4
unnamed: Converter1.17 (A6), J14.3
unnamed: Converter1.18 (A7), J14.2
unnamed: Converter1.19 (A8), J14.1
unnamed: Converter1.4 (B3), J13.6
unnamed: Converter1.5 (B4), J13.5
unnamed: Converter1.6 (B5), J13.4
unnamed: Converter1.7 (B6), J13.3
unnamed: Converter1.8 (B7), J13.2
unnamed: Converter1.9 (B8), J13.1
unnamed: Converter1.20 (OE), R6.2
unnamed: D1.4 (BA), R1.1
unnamed: D1.3 (GA), R3.1
unnamed: D1.1 (RA), R4.1
unnamed: D2.4 (BA), R10.1
unnamed: D2.3 (GA), R11.1
unnamed: D2.1 (RA), R12.1
unnamed: ESP_CTR1.D34, R8.2
unnamed: ESP_CTR1.D35, R9.2

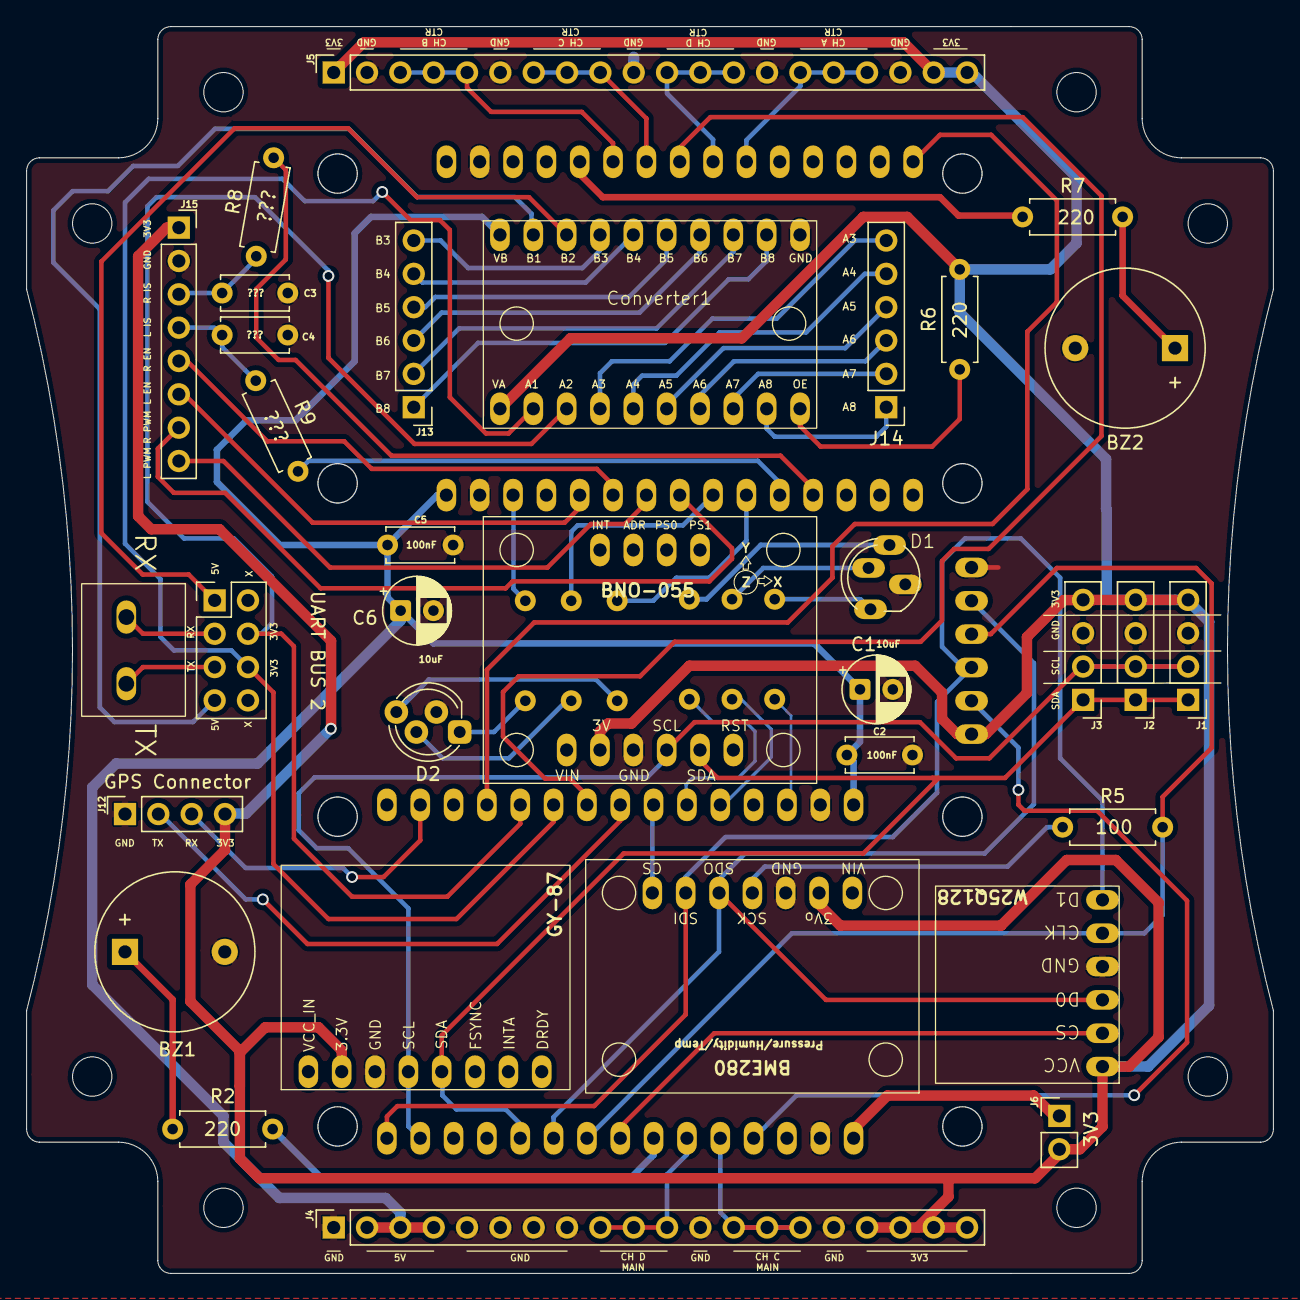
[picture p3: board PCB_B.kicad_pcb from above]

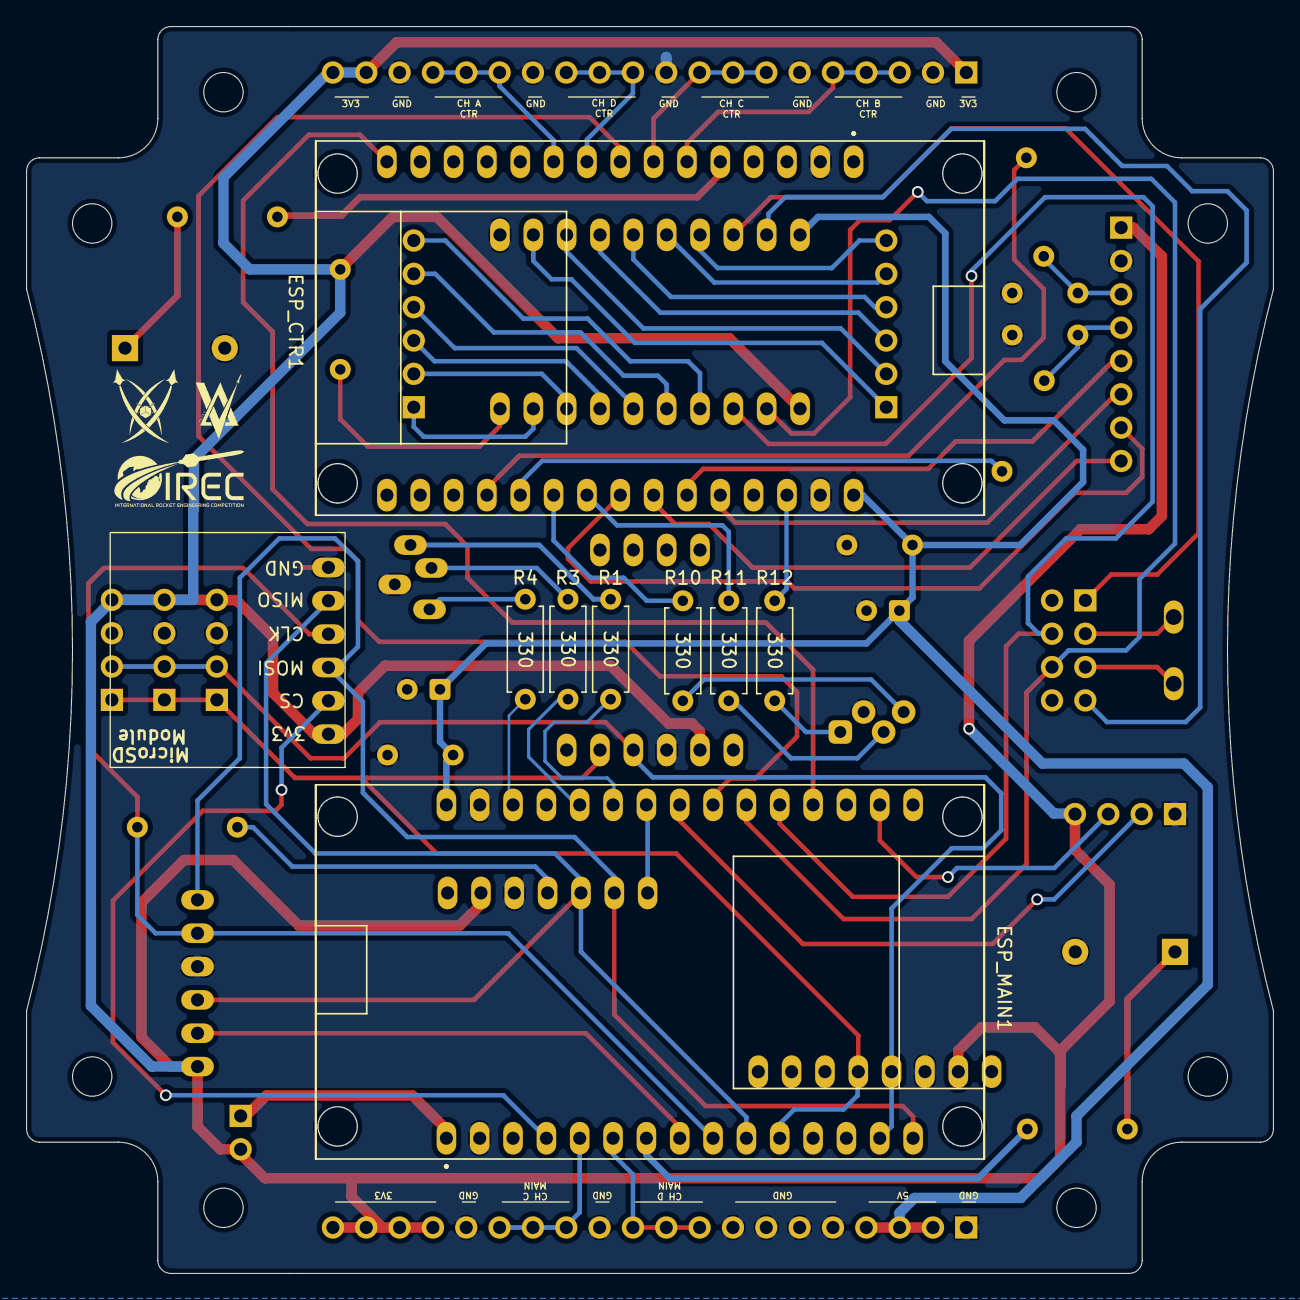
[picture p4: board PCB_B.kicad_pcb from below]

Board: 2 copper layers, 95.0 x 95.0 mm, 42 parts (9 on the bottom side), 66 nets.

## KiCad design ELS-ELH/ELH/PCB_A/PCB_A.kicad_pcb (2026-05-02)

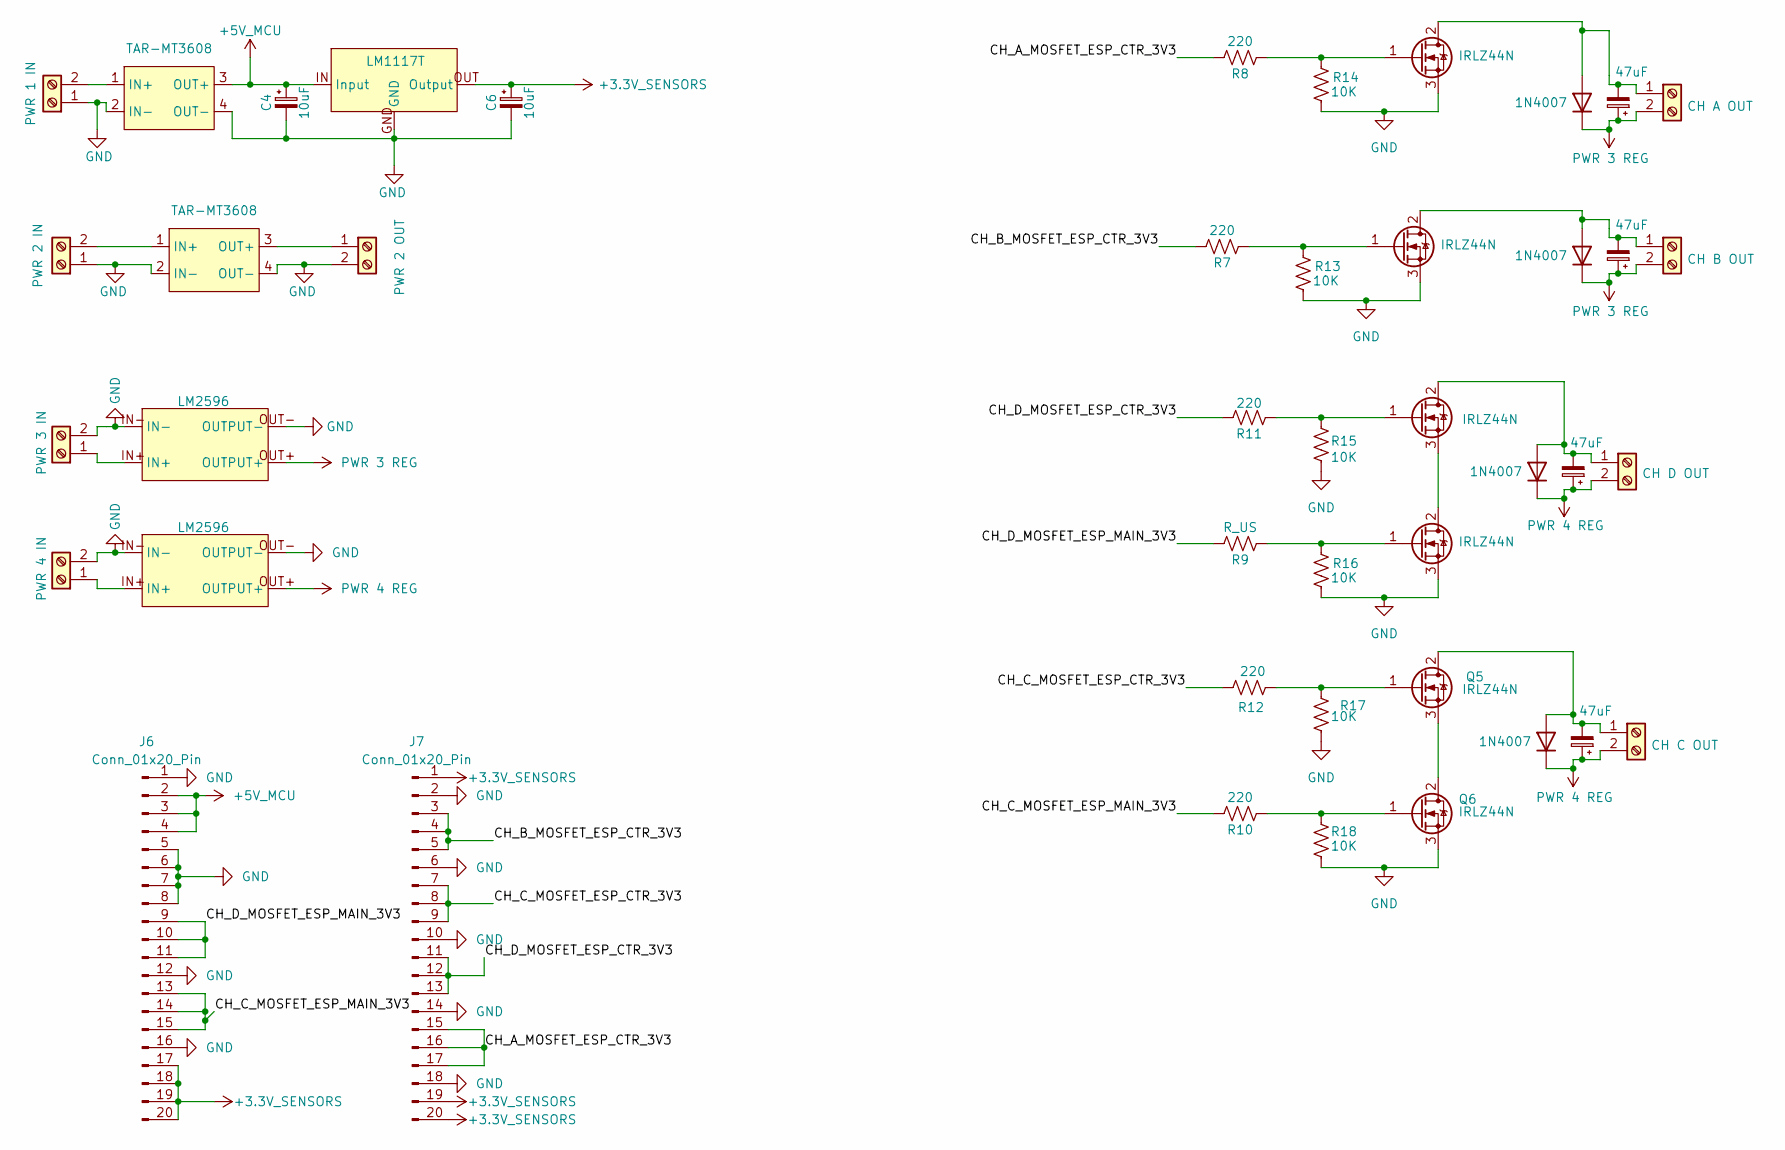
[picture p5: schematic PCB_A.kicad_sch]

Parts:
BOOST1, BOOST2: TAR-MT3608
C4, C6: 10uF; CP_Radial_D5.0mm_P2.00mm
C7, C8, C9, C10: 47uF; CP_Radial_D6.3mm_P2.50mm
D2, D3, D4, D5: 1N4007; D_DO-41_SOD81_P10.16mm_Horizontal
J1: PWR 1 IN; Bornera 2P
J2: PWR 2 IN; Bornera 2P
J3: PWR 3 IN; Bornera 2P
J4: PWR 4 IN; Bornera 2P
J5: PWR 2 OUT; Bornera 2P
J6, J7: Conn_01x20_Pin; PinHeader_1x20_P2.54mm_Vertical
J9: CH D OUT; Bornera 2P
J10: CH C OUT; Bornera 2P
J11: CH A OUT; Bornera 2P
J12: CH B OUT; Bornera 2P
Q1, Q2, Q3, Q4, Q5, Q6: IRLZ44N; TO-220-3_Vertical
R7, R8, R10, R11, R12: 220; R_Axial_DIN0207_L6.3mm_D2.5mm_P7.62mm_Horizontal
R9: R_US; R_Axial_DIN0207_L6.3mm_D2.5mm_P7.62mm_Horizontal
R13, R14, R15, R16, R17, R18: 10K; R_Axial_DIN0207_L6.3mm_D2.5mm_P7.62mm_Horizontal
Regulator1, Regulator2: LM2596
Regulator3: LM1117T

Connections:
+3.3V_SENSORS: C6.1, J6.17, J6.18, J6.19, J6.20, J7.1, J7.19, J7.20, Regulator3.OUT (Output)
+5V_MCU: BOOST1.3 (OUT+), C4.1, J6.2, J6.3, J6.4, Regulator3.IN (Input)
/CH_A_MOSFET_ESP_CTR_3V3: J7.15, J7.16, J7.17, R8.1
/CH_B_MOSFET_ESP_CTR_3V3: J7.3, J7.4, J7.5, R7.1
/CH_C_MOSFET_ESP_CTR_3V3: J7.7, J7.8, J7.9, R12.1
/CH_C_MOSFET_ESP_MAIN_3V3: J6.13, J6.14, J6.15, R10.1
/CH_D_MOSFET_ESP_CTR_3V3: J7.11, J7.12, J7.13, R11.1
/CH_D_MOSFET_ESP_MAIN_3V3: J6.9, J6.10, J6.11, R9.1
GND: BOOST1.2 (IN-), BOOST1.4 (OUT-), BOOST2.2 (IN-), BOOST2.4 (OUT-), C4.2, C6.2, J1.1, J2.1, J3.2, J4.2, J5.2, J6.1, J6.5, J6.6, J6.7, J6.8, J6.12, J6.16, J7.2, J7.6, J7.10, J7.14, J7.18, Q1.3 (S), Q2.3 (S), Q4.3 (S), Q6.3 (S), R13.2, R14.2, R15.2, R16.2, R17.2, R18.2, Regulator1.IN-, Regulator1.OUT- (OUTPUT-), Regulator2.IN-, Regulator2.OUT- (OUTPUT-), Regulator3.GND
unnamed: BOOST1.1 (IN+), J1.2
unnamed: BOOST2.1 (IN+), J2.2
unnamed: BOOST2.3 (OUT+), J5.1
unnamed: C7.2, D2.2 (A), J9.1, Q3.2 (D)
unnamed: C8.2, D3.2 (A), J10.1, Q5.2 (D)
unnamed: C9.2, D4.2 (A), J11.1, Q2.2 (D)
unnamed: C10.2, D5.2 (A), J12.1, Q1.2 (D)
unnamed: J3.1, Regulator1.IN+
unnamed: J4.1, Regulator2.IN+
unnamed: Q1.1 (G), R7.2, R13.1
unnamed: Q2.1 (G), R8.2, R14.1
unnamed: Q3.1 (G), R11.2, R15.1
unnamed: Q3.3 (S), Q4.2 (D)
unnamed: Q4.1 (G), R9.2, R16.1
unnamed: Q5.1 (G), R12.2, R17.1
unnamed: Q5.3 (S), Q6.2 (D)
unnamed: Q6.1 (G), R10.2, R18.1
PWR 3 REG: C9.1, C10.1, D4.1 (K), D5.1 (K), J11.2, J12.2, Regulator1.OUT+ (OUTPUT+)
PWR 4 REG: C7.1, C8.1, D2.1 (K), D3.1 (K), J9.2, J10.2, Regulator2.OUT+ (OUTPUT+)

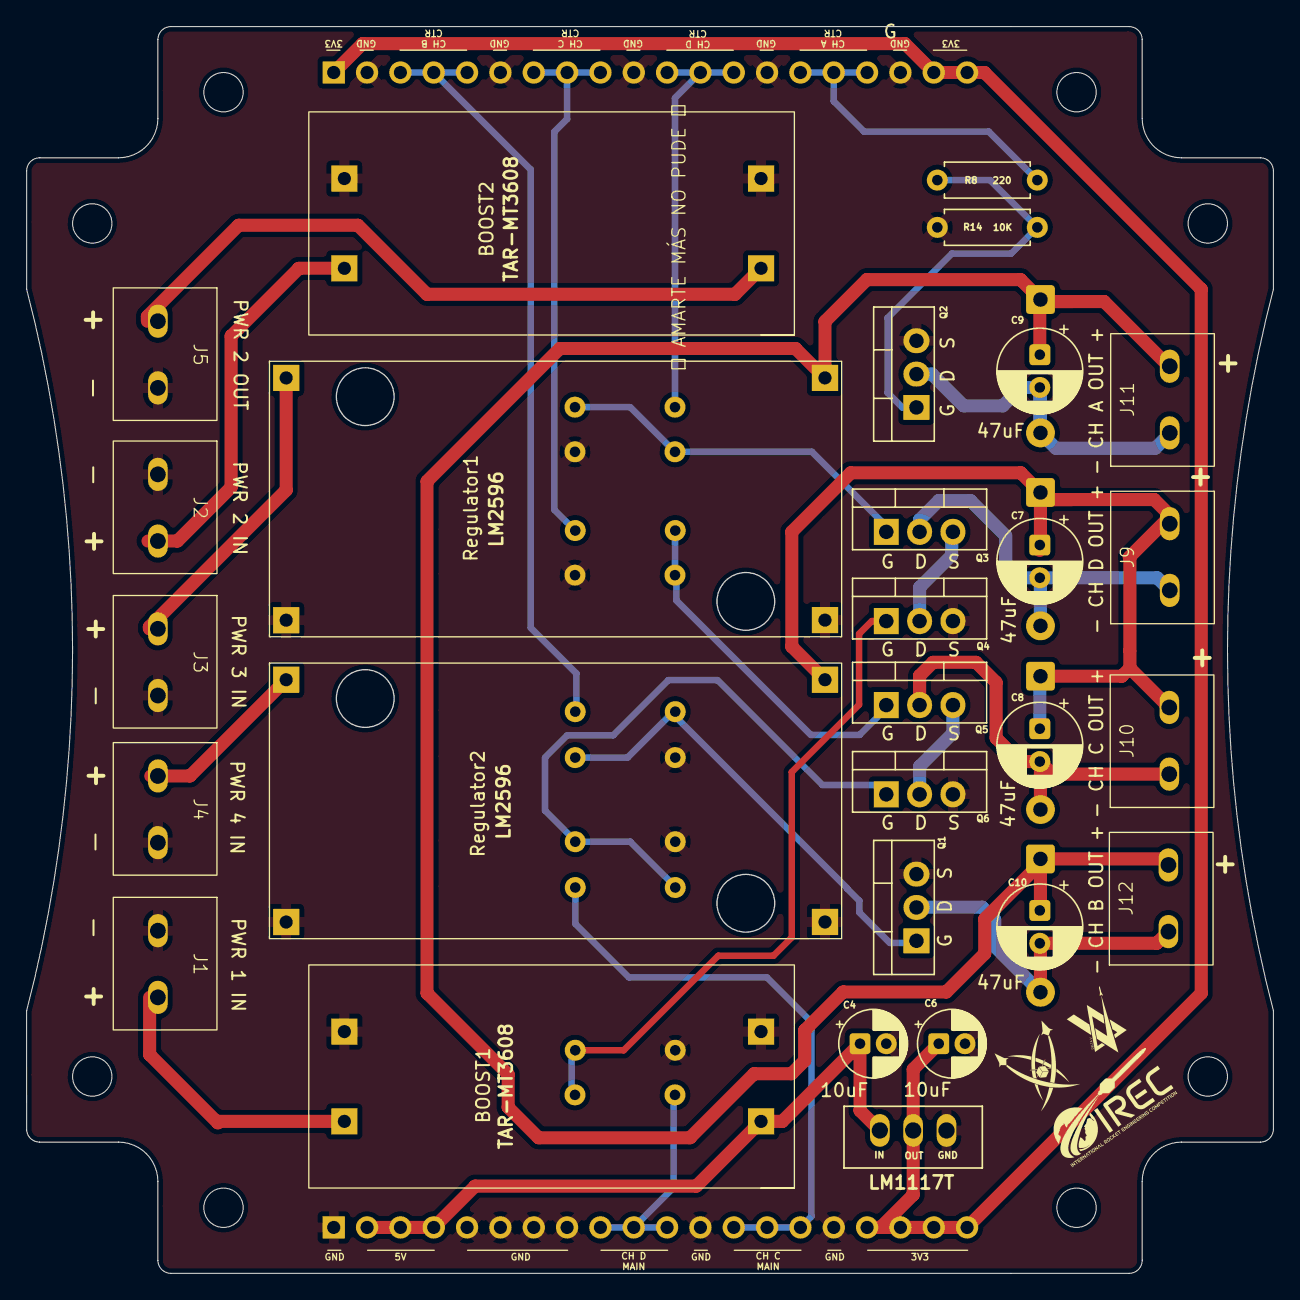
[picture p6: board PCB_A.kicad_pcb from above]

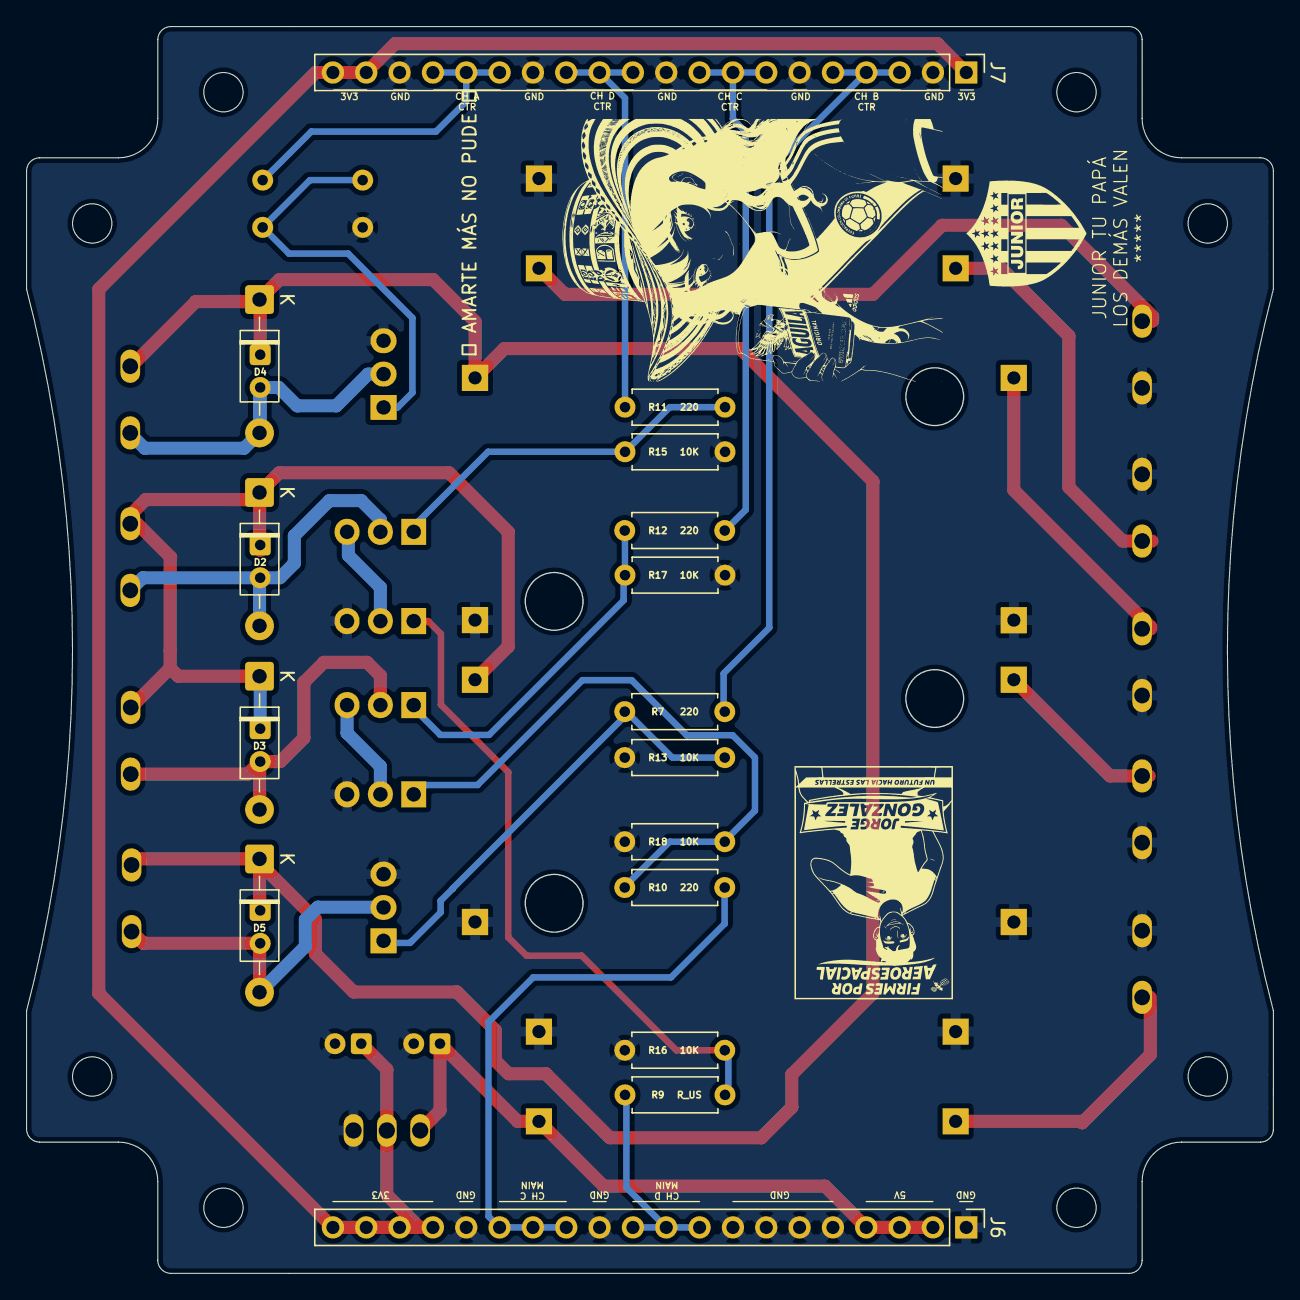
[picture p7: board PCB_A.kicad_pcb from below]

Board: 2 copper layers, 95.0 x 95.0 mm, 44 parts (16 on the bottom side), 28 nets.

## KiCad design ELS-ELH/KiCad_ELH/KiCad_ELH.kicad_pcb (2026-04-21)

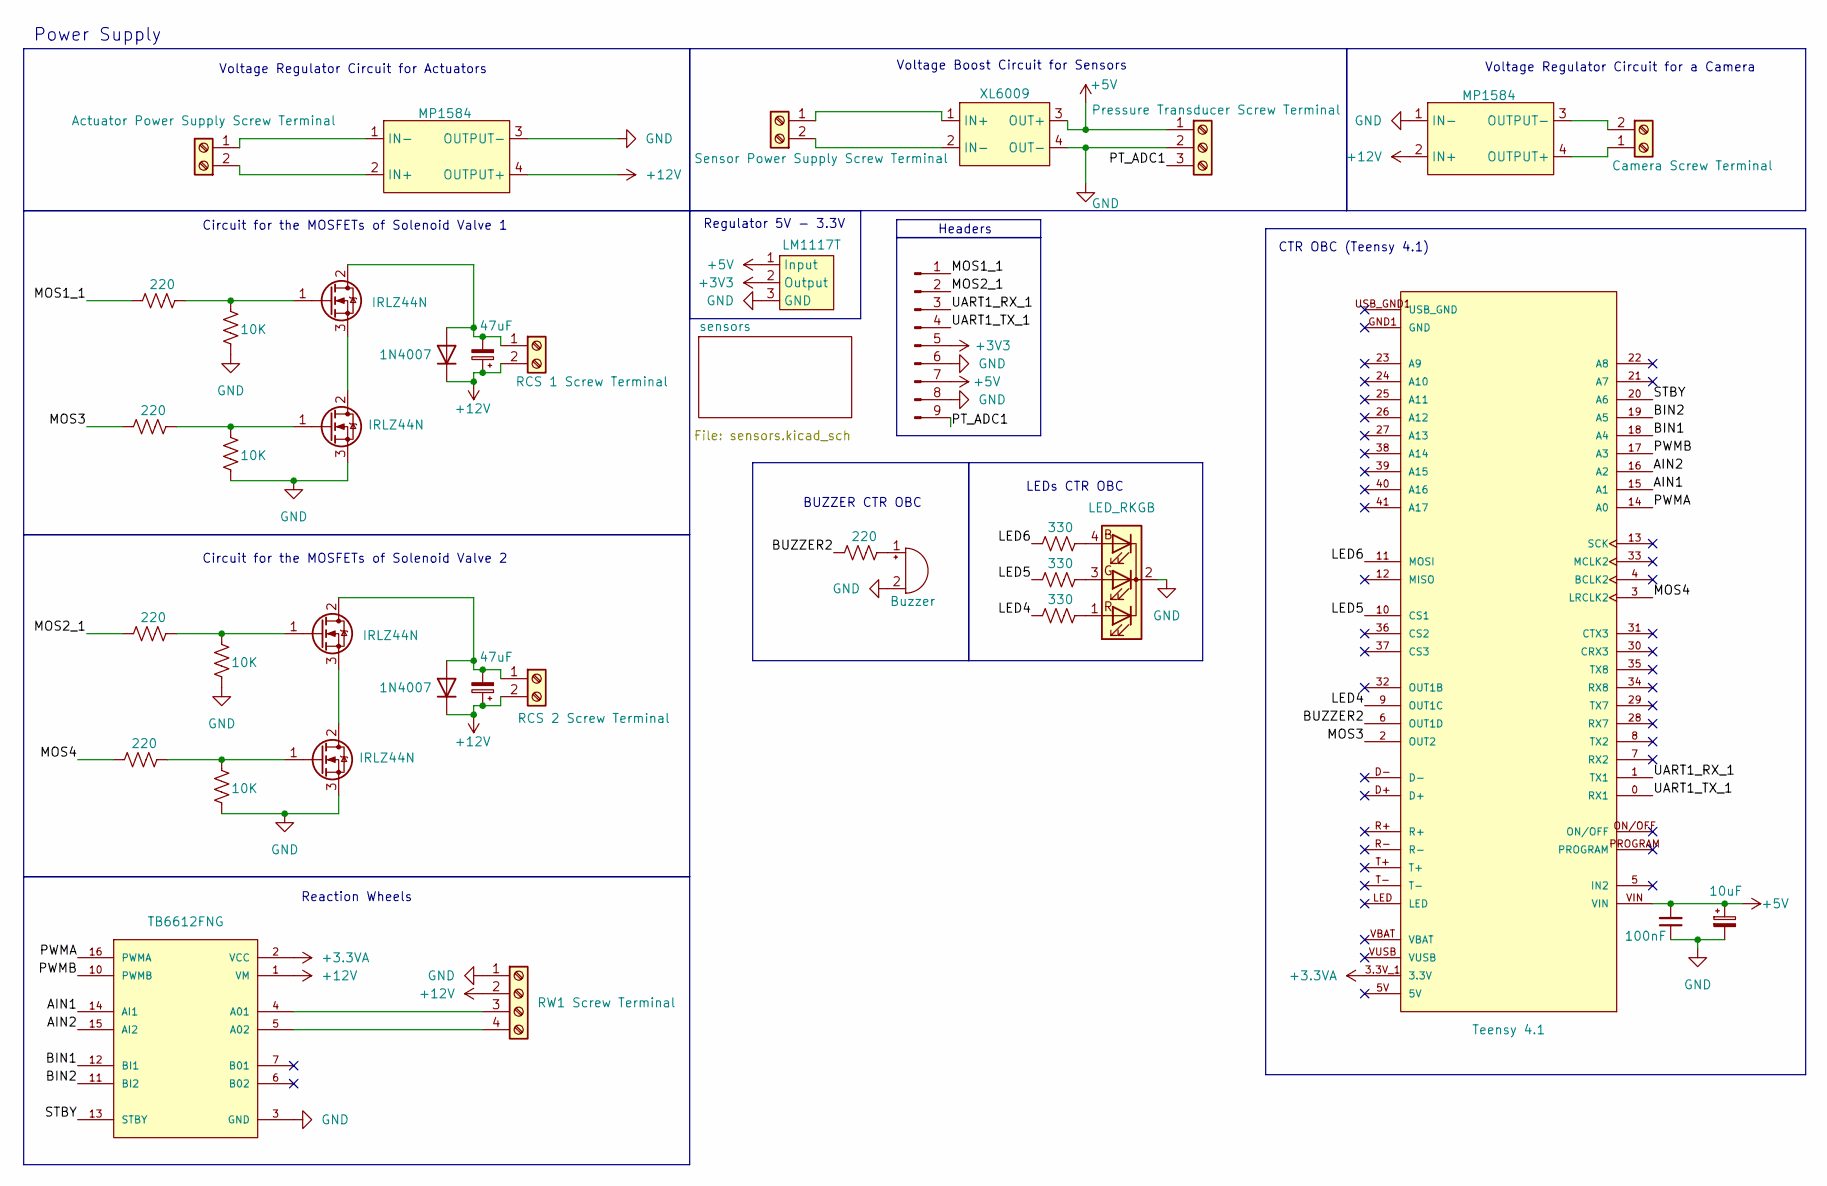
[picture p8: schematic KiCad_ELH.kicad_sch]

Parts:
BOOST1: XL6009; XL6009 Boost
BZ2: Buzzer; Buzzer_12x9.5RM7.6
Bornera2: Camera Screw Terminal; Bornera 2P
Bornera3: Actuator Power Supply Screw Terminal; Bornera 2P
Bornera4: RCS 2 Screw Terminal; Bornera 2P
Bornera5: RCS 1 Screw Terminal; Bornera 2P
Bornera6: Sensor Power Supply Screw Terminal; Bornera 2P
C1: 100nF; C_Disc_D5.0mm_W2.5mm_P5.00mm
C3: 10uF; CP_Radial_D5.0mm_P2.50mm
C9, C10: 47uF; CP_Radial_D6.3mm_P2.50mm
D1, D9: 1N4007; D_DO-41_SOD81_P10.16mm_Horizontal
D3: LED_RKGB; LED_D5.0mm-4_RGB_Staggered_Pins
Driver_DC2: TB6612FNG
J1: Pressure Transducer Screw Terminal; TerminalBlock_MaiXu_MX126-5.0-03P_1x03_P5.00mm
J2: Conn_01x09_Pin; Hirose_DF13-09P-1.25DSA_1x09_P1.25mm_Vertical
J8: RW1 Screw Terminal; TerminalBlock_MaiXu_MX126-5.0-04P_1x04_P5.00mm
Q1, Q2, Q4, Q6: IRLZ44N; TO-220-3_Vertical
R1, R2, R8: 330; R_Axial_DIN0207_L6.3mm_D2.5mm_P7.62mm_Horizontal
R3, R6, R9, R16, R20: 220; R_Axial_DIN0207_L6.3mm_D2.5mm_P7.62mm_Horizontal
R10, R11, R18, R19: 10K; R_Axial_DIN0207_L6.3mm_D2.5mm_P7.62mm_Horizontal
Regulator1: LM1117T
Regulator3, Regulator4: MP1584
Teensy3: Teensy 4.1

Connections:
+3.3VA: Driver_DC2.2 (VCC), Teensy3.3.3V_1 (3.3V), Teensy3.3.3V_2 (3.3V), Teensy3.3.3V_3 (3.3V)
+3V3: J2.5, Regulator1.2 (Output)
+5V: BOOST1.3 (OUT+), C1.2, C3.1, J1.1, J2.7, Regulator1.1 (Input), Teensy3.VIN
+12V: Bornera4.2, Bornera5.2, C9.1, C10.1, D1.1 (K), D9.1 (K), Driver_DC2.1 (VM), J8.2, Regulator3.2 (IN+), Regulator4.4 (OUTPUT+)
/AIN1: Driver_DC2.14 (AI1), Teensy3.15 (A1)
/AIN2: Driver_DC2.15 (AI2), Teensy3.16 (A2)
/BIN1: Driver_DC2.12 (BI1), Teensy3.18 (A4)
/BIN2: Driver_DC2.11 (BI2), Teensy3.19 (A5)
/BUZZER2: R9.1, Teensy3.6 (OUT1D)
/LED4: R8.2, Teensy3.9 (OUT1C)
/LED5: R2.2, Teensy3.10 (CS1)
/LED6: R1.2, Teensy3.11 (MOSI)
/MOS1_1: J2.1, R16.1
/MOS2_1: J2.2, R6.1
/MOS3: R20.1, Teensy3.2 (OUT2)
/MOS4: R3.1, Teensy3.3 (LRCLK2)
/PT_ADC1: J1.3, J2.9
/PWMA: Driver_DC2.16 (PWMA), Teensy3.14 (A0)
/PWMB: Driver_DC2.10 (PWMB), Teensy3.17 (A3)
/STBY: Driver_DC2.13 (STBY), Teensy3.20 (A6)
/UART1_RX_1: J2.3, Teensy3.1 (TX1)
/UART1_TX_1: J2.4, Teensy3.0 (RX1)
unnamed: BOOST1.1 (IN+), Bornera6.1 (Pin_2)
unnamed: BOOST1.2 (IN-), Bornera6.2 (Pin_1)
unnamed: BZ2.1 (+), R9.2
unnamed: Bornera2.2 (Pin_1), Regulator3.3 (OUTPUT-)
unnamed: Bornera2.1 (Pin_2), Regulator3.4 (OUTPUT+)
unnamed: Bornera3.2 (Pin_1), Regulator4.2 (IN+)
unnamed: Bornera3.1 (Pin_2), Regulator4.1 (IN-)
unnamed: Bornera4.1, C10.2, D1.2 (A), Q1.2 (D)
unnamed: Bornera5.1, C9.2, D9.2 (A), Q6.2 (D)
unnamed: D3.4 (BA), R1.1
unnamed: D3.3 (GA), R2.1
unnamed: D3.1 (RA), R8.1
unnamed: Driver_DC2.4 (A01), J8.3
unnamed: Driver_DC2.5 (A02), J8.4
unnamed: Q1.1 (G), R6.2, R10.1
unnamed: Q1.3 (S), Q4.2 (D)
unnamed: Q2.2 (D), Q6.3 (S)
unnamed: Q2.1 (G), R19.1, R20.2
unnamed: Q4.1 (G), R3.2, R11.1
unnamed: Q6.1 (G), R16.2, R18.1

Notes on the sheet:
Regulator 5V - 3.3V
Reaction Wheels
Circuit for the MOSFETs of Solenoid Valve 2
Power Supply
Voltage Regulator Circuit for a Camera
BUZZER CTR OBC
LEDs CTR OBC
Voltage Regulator Circuit for Actuators
Headers
Circuit for the MOSFETs of Solenoid Valve 1
CTR OBC (Teensy 4.1)
Voltage Boost Circuit for Sensors

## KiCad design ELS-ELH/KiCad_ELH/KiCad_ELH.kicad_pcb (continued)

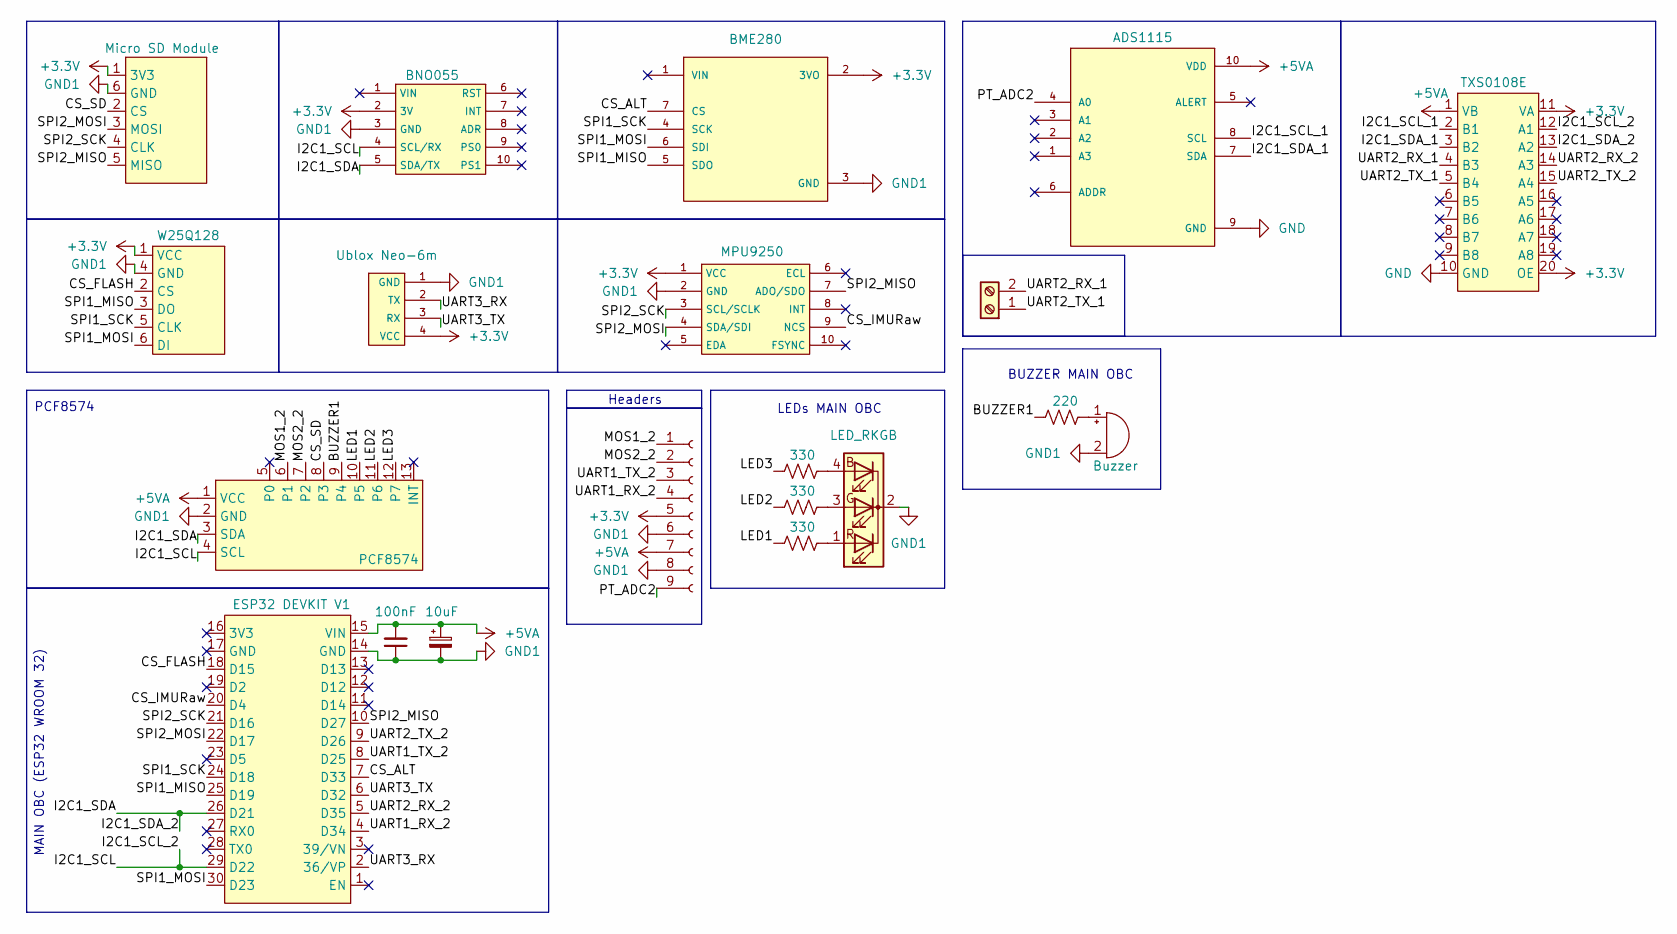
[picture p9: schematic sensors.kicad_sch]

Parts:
ADC1: ADS1115
Adapter1: PCF8574
BME2: BME280
BZ1: Buzzer; Buzzer_12x9.5RM7.6
Bornera7: COM Camera Screw Terminal; Bornera 2P
C2: 100nF; C_Disc_D5.0mm_W2.5mm_P5.00mm
C13: 10uF; CP_Radial_D5.0mm_P2.50mm
Converter1: TXS0108E
D10: LED_RKGB; LED_D5.0mm-4_RGB_Staggered_Pins
ESP1: ESP32 DEVKIT V1
GPS1: Ublox Neo-6m
IMU1: MPU9250
IMU3: BNO055
J11: Conn_01x09_Socket; Hirose_DF13-09P-1.25DSA_1x09_P1.25mm_Vertical
R4, R5, R7: 330; R_Axial_DIN0207_L6.3mm_D2.5mm_P7.62mm_Horizontal
R12: 220; R_Axial_DIN0207_L6.3mm_D2.5mm_P7.62mm_Horizontal
SD_Adapter1: Micro SD Module; MicroSD Module
W25QXX1: W25Q128

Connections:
+3.3V: BME2.2 (3VO), Converter1.11 (VA), Converter1.20 (OE), GPS1.4 (VCC), IMU1.1 (VCC), IMU3.2 (3V), J11.5, SD_Adapter1.1 (3V3), W25QXX1.1 (VCC)
+5VA: ADC1.10 (VDD), Adapter1.1 (VCC), C2.2, C13.1, Converter1.1 (VB), ESP1.15 (VIN), J11.7
/sensors/BUZZER1: Adapter1.9 (P4), R12.1
/sensors/CS_ALT: BME2.7 (CS), ESP1.7 (D33)
/sensors/CS_FLASH: ESP1.18 (D15), W25QXX1.2 (CS)
/sensors/CS_IMURaw: ESP1.20 (D4), IMU1.9 (NCS)
/sensors/CS_SD: Adapter1.8 (P3), SD_Adapter1.2 (CS)
/sensors/I2C1_SCL: Adapter1.4 (SCL), Converter1.12 (A1), ESP1.29 (D22), IMU3.4 (SCL/RX)
/sensors/I2C1_SCL_1: ADC1.8 (SCL), Converter1.2 (B1)
/sensors/I2C1_SDA: Adapter1.3 (SDA), Converter1.13 (A2), ESP1.26 (D21), IMU3.5 (SDA/TX)
/sensors/I2C1_SDA_1: ADC1.7 (SDA), Converter1.3 (B2)
/sensors/LED1: Adapter1.10 (P5), R4.2
/sensors/LED2: Adapter1.11 (P6), R5.2
/sensors/LED3: Adapter1.12 (P7), R7.2
/sensors/MOS1_2: Adapter1.6 (P1), J11.1
/sensors/MOS2_2: Adapter1.7 (P2), J11.2
/sensors/PT_ADC2: ADC1.4 (A0), J11.9
/sensors/SPI1_MISO: BME2.5 (SDO), ESP1.25 (D19), W25QXX1.3 (DO)
/sensors/SPI1_MOSI: BME2.6 (SDI), ESP1.30 (D23), W25QXX1.6 (DI)
/sensors/SPI1_SCK: BME2.4 (SCK), ESP1.24 (D18), W25QXX1.5 (CLK)
/sensors/SPI2_MISO: ESP1.10 (D27), IMU1.7 (ADO/SDO), SD_Adapter1.5 (MISO)
/sensors/SPI2_MOSI: ESP1.22 (D17), IMU1.4 (SDA/SDI), SD_Adapter1.3 (MOSI)
/sensors/SPI2_SCK: ESP1.21 (D16), IMU1.3 (SCL/SCLK), SD_Adapter1.4 (CLK)
/sensors/UART1_RX_2: ESP1.4 (D34), J11.4
/sensors/UART1_TX_2: ESP1.8 (D25), J11.3
/sensors/UART2_RX_1: Bornera7.2, Converter1.4 (B3)
/sensors/UART2_RX_2: Converter1.14 (A3), ESP1.5 (D35)
/sensors/UART2_TX_1: Bornera7.1, Converter1.5 (B4)
/sensors/UART2_TX_2: Converter1.15 (A4), ESP1.9 (D26)
/sensors/UART3_RX: ESP1.2 (36/VP), GPS1.2 (TX)
/sensors/UART3_TX: ESP1.6 (D32), GPS1.3 (RX)
GND1: Adapter1.2 (GND), BME2.3 (GND), BZ1.2 (-), C2.1, C13.2, D10.2 (K), ESP1.14 (GND), GPS1.1 (GND), IMU1.2 (GND), IMU3.3 (GND), J11.6, J11.8, SD_Adapter1.6 (GND), W25QXX1.4 (GND)
unnamed: BZ1.1 (+), R12.2
unnamed: D10.4 (BA), R7.1
unnamed: D10.3 (GA), R5.1
unnamed: D10.1 (RA), R4.1

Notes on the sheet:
BUZZER MAIN OBC
Headers
LEDs MAIN OBC
MAIN OBC (ESP32 WROOM 32)
PCF8574

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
Board: 2 copper layers, 58 parts (2 on the bottom side), 79 nets, no tracks yet.

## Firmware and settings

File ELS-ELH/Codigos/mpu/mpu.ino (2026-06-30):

#include <MPU6050_light.h>
#include <Adafruit_BMP085.h>
#include <DFRobot_QMC5883.h>
#include <Adafruit_BNO055.h>

MPU6050 mpu(Wire);
Adafruit_BMP085 bmp;
Adafruit_BNO055 bno;

struct StructBNO055{
    uint32_t timestamp; ///< Reading timestamp in ms
    float BNO_ax;       ///< Acceleration on the X axis
    float BNO_ay;       ///< Acceleration on the Y axis
    float BNO_az;       ///< Acceleration on the Z axis
    float BNO_gx;       ///< Angular velocity on the X axis
    float BNO_gy;       ///< Angular velocity on the Y axis
    float BNO_gz;       ///< Angular velocity on the Z axis
    float BNO_mx;       ///< Magnetic field on the X axis
    float BNO_my;       ///< Magnetic field on the Y axis
    float BNO_mz;       ///< Magnetic field on the Z axis
    float BNO_qw;       ///< Quaternion orientation W component
    float BNO_qx;       ///< Quaternion orientation X component
    float BNO_qy;       ///< Quaternion orientation Y component
    float BNO_qz;       ///< Quaternion orientation Z component
};

struct StructMPU6050{
    uint32_t timestamp;  ///< Reading timestamp in ms
    float MPU_ax;        ///< Acceleration on the X axis
    float MPU_ay;        ///< Acceleration on the Y axis
    float MPU_az;        ///< Acceleration on the Z axis
    float MPU_gx;        ///< Angular velocity on the X axis
    float MPU_gy;        ///< Angular velocity on the Y axis
    float MPU_gz;        ///< Angular velocity on the Z axis
    float MPU_temp;      ///< Internal chip temperature
};

struct StructBMP180{
    uint32_t timestamp;  ///< Reading timestamp in ms
    float temp;          ///< Temperature in Celsius degrees
    float pressure;      ///< Atmospheric pressure in Pa
    float altitude;      ///< Calculated altitude in meters
};
struct StructQMC5883L{
    uint32_t timestamp; ///< Reading timestamp in ms
    float QMC_mx;       ///< Magnetic field on the X axis
    float QMC_my;       ///< Magnetic field on the Y axis
    float QMC_mz;       ///< Magnetic field on the Z axis
};

StructMPU6050 mpuData; 
StructBMP180 bmpData; 
StructBNO055 bnoData;
StructQMC5883L qmcData;

void InitMPU6050(){
  Wire.begin();
  byte status = mpu.begin();
  if (status != 0) {
      Serial.println("MPU6050 initialization failed");
  } else {
      Serial.println("MPU6050 sensor initialized successfully");
  };
}

void InitBMP180(){
   Wire.begin();
    if (!bmp.begin()) {
	    Serial.println("BMP180 initialization failed");
    } else {
        Serial.println("BMP180 sensor initialized successfully");
    };
}
void InitQMC5883L(){
    Wire.beginTransmission(0x68); 
    Wire.write(0x37);
    Wire.write(0x02); 
    if (Wire.endTransmission() != 0) {
        Serial.println("Failed to open MPU6050 Bypass");
        return;
    }

    Wire.beginTransmission(0x0D); 
    Wire.write(0x09); 
    Wire.write(0x1D); 
    Wire.endTransmission();

    Wire.beginTransmission(0x0D);
    Wire.write(0x0B);
    Wire.write(0x01); 
    
    if (Wire.endTransmission() != 0) {
        Serial.println("QMC5883L not found on 0x0D");
    } else {
        Serial.println("QMC5883L initialized successfully");
    }
}
void InitBNO055() {
    // Code to initialize BNO055 sensor
    if (!bno.begin()) {
        Serial.println("BNO055 initialization failed");
    } else {
        Serial.println("BNO055 sensor initialized successfully");
    };
}



void ReadMPU6050(){
    mpu.update();
    mpuData.timestamp = millis();

    // Codigo calibrado y en m/s2 y rad/s
    float ax_g = mpu.getAccX();
    float ay_g = mpu.getAccY();
    float az_g = mpu.getAccZ();

    mpuData.MPU_ax = ax_g * 9.80665;
    mpuData.MPU_ay = ay_g * 9.80665;
    mpuData.MPU_az = az_g * 9.80665;

    float gx_deg = mpu.getGyroX();
    float gy_deg = mpu.getGyroY();
    float gz_deg = mpu.getGyroZ();

    mpuData.MPU_gx = gx_deg * 0.0174533;
    mpuData.MPU_gy = gy_deg * 0.0174533;
    mpuData.MPU_gz = gz_deg * 0.0174533;

}

void ReadBMP180(){
    float pressurePad1 = // sea level
    bmpData.timestamp = millis();
    bmpData.temp = bmp.readTemperature();
    bmpData.pressure = bmp.readPressure();
    bmpData.altitude = bmp.readAltitude(pressurePad1);
}
void ReadQMC5883L(){
    Wire.beginTransmission(0x0D);
    Wire.write(0x00);
    Wire.endTransmission();
    Wire.requestFrom(0x0D, 6);

    if (Wire.available() == 6) {
        int16_t rawX = (int16_t)(Wire.read() | (Wire.read() << 8));
        int16_t rawY = (int16_t)(Wire.read() | (Wire.read() << 8));
        int16_t rawZ = (int16_t)(Wire.read() | (Wire.read() << 8));

        qmcData.timestamp = millis();

        float correctedX = (rawX);
        float correctedY = (rawY);
        float correctedZ = (rawZ);

        qmcData.timestamp = millis();

        qmcData.QMC_mx = (correctedX / 3000.0f) * 1e-4f;
        qmcData.QMC_my = (correctedY / 3000.0f) * 1e-4f;
        qmcData.QMC_mz = (correctedZ / 3000.0f) * 1e-4f;
    }
}

void ReadBNO055() {
    // Code to read data from BNO055 sensor
    bnoData.timestamp = millis();
    imu::Vector<3> lin_accel = bno.getVector(Adafruit_BNO055::VECTOR_LINEARACCEL);
    bnoData.BNO_ax = lin_accel.x();
    bnoData.BNO_ay = lin_accel.y();
    bnoData.BNO_az = lin_accel.z();
    imu::Vector<3> gyro = bno.getVector(Adafruit_BNO055::VECTOR_GYROSCOPE);
    bnoData.BNO_gx = gyro.x() * 0.0174533;
    bnoData.BNO_gy = gyro.y() * 0.0174533;
    bnoData.BNO_gz = gyro.z() * 0.0174533;
    imu::Vector<3> mag = bno.getVector(Adafruit_BNO055::VECTOR_MAGNETOMETER);
    bnoData.BNO_mx = mag.x() * 1e-6;
    bnoData.BNO_my = mag.y() * 1e-6;
    bnoData.BNO_mz = mag.z() * 1e-6;
     imu::Quaternion quat = bno.getQuat();
    bnoData.BNO_qw = quat.w();
    bnoData.BNO_qx = quat.x();
    bnoData.BNO_qy = quat.y();
    bnoData.BNO_qz = quat.z();
    
    imu::Vector<3> mag = bno.getVector(Adafruit_BNO055::VECTOR_MAGNETOMETER);
    bnoData.BNO_mx = mag.x() * 1e-6;
    bnoData.BNO_my = mag.y() * 1e-6;
    bnoData.BNO_mz = mag.z() * 1e-6;
}

void setup() {
  Serial.begin(115200);
  delay(1000);
  InitMPU6050();
  InitBMP180();
  InitQMC5883L();



}

void loop() {


}

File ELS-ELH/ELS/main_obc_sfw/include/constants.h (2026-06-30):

#pragma once

#include <stdint.h>

/**
 * @brief Pins definitions and data structure definitions.
 *
 * This file contains all the pin configurations for the sensors (GY87, BNO055, BME280, UBLOX),
 * memory configuration (Flash, SD), actuators, and the necessary structures to store telemetry and calibration data.
 */

/** @name Baud Rates */ 
#define BAUD_RATE 115200  ///< Baude rate for the main serial monitor
#define GPS_BAUD 9600  ///< Baud rate for the Ublox GPS module

//============================
// PIN DEFINITIONS (HARDWARE)
//============================

/** @name GY87 MODULE (MPU6050, QMC5883L, BMP180) */
#define GY_SCL 22  ///< I2C Clock pin for the GY87
#define GY_SDA 21  ///< I2C Data pin for the GY87

/** @name BNO055 SENSOR */
#define BNO_SDA 21  ///< I2C Clock pin for the BNO055
#define BNO_SCL 22  ///< I2C Data pin for the BNO055

/** @name BME280 SENSOR */
#define BME_SCK 18   ///< SPI Clock pin for the BME280
#define BME_MOSI 23  ///< SPI Mosi pin for the BME280
#define BME_MISO 19  ///< SPI Miso pin for the BME280
#define BME_CS 26    ///< SPI Chip select pin for the BME280

/** @name UBLOX GPS Module */
#define UBLOX_TX 25  ///< Transmission pin (TX) to the GPS
#define UBLOX_RX 36  ///< Reception pin (RX) to the GPS

/** @name EXTERNAL FLASH MEMORY */
#define FLASH_SCK 18   ///< SPI Clock pin for the FLASH MEMORY
#define FLASH_MOSI 23  ///< SPI Mosi pin for the FLASH MEMORY
#define FLASH_MISO 19  ///< SPI Miso pin for the FLASH MEMORY
#define FLASH_CS 5     ///< SPI Chip select pin for the FLASH MEMORY

/** @name SD CARD MODULE */
#define SD_SCK 18   ///< SPI Clock pin for the SD CARD
#define SD_MOSI 22  ///< SPI Mosi pin for the SD CARD
#define SD_MISO 19  ///< SPI Miso pin for the SD CARD
#define SD_CS  2    ///< SPI Chip select pin for the SD CARD

/** @name ACTUATORS */
#define ACTUATOR1_PIN 16 ///< Control pin for Actuator 1
#define ACTUATOR2_PIN 4  ///< Control pin for Actuator 2

/** @name RGB LED PINS */
#define LED_RED_PIN 13   ///< Physical pin for the RGB LED red color
#define LED_GREEN_PIN 14 ///< Physical pin for the RGB LED green color
#define LED_BLUE_PIN 27  ///< Physical pin for the RGB LED blue color

/** @name BUZZER PIN*/ 
#define BUZZER_PIN 17  ///< Physical pin for the BUZZER

// ==================
// PWM CONFIGURATION
// ==================

/** @name PWM CHANELS AND PARAMETERS */
#define RED_CHANNEL 0      ///< Internal PWM channel for the Red LED
#define GREEN_CHANNEL 1    ///< Internal PWM channel for the Green LED
#define BLUE_CHANNEL 2     ///< Internal PWM channel for the Blue LED
#define BUZZER_CHANNEL 3   ///< Internal PWM channel for the Buzzer

#define PWM_FREQ 5000      ///< Base PWM signal frequency in Hz
#define PWM_RESOLUTION 8   ///< PWM resolution in bits

// ===========================
// FLIGHT COMPUTER PARAMETERS
// ===========================

/** @name FLIGHT LOGIC AND SAMPLING */
#define LAUNCH_ACCEL_THRESHOLD_MS2 19.6133f ///< Acceleration threshold to detect launch
#define MACH_VELOCITY_THRESHOLD_MS2 250.0f
#define FAST_SAMPLE_INTERVAL_MS 10          ///< Fast sampling interval in milliseconds
#define SLOW_SAMPLE_INTERVAL_MS 1000        ///< Slow sampling interval in milliseconds

// ======================
// FLASH MEMORY COMMANDS
// ======================

/** @name FLASH COMMANDS AND DEFINITIONS */
#define FLASH_PAGE_SIZE 256UL        ///< Flash memory page size in bytes
#define FLASH_TOTAL_BYTES 4194304UL ///< Total Flash memory capacity

#define CMD_WRITE_ENABLE 0x06        ///< SPI Command: Write enable
#define CMD_CHIP_ERASE 0xC7          ///< SPI Command: Chip erase
#define CMD_PAGE_PROGRAM 0x02        ///< SPI Command: Page program
#define CMD_READ_DATA 0x03           ///< SPI Command: Read data
#define CMD_READ_STATUS 0x05         ///< SPI Command: Read status register
#define CMD_JEDEC_ID 0x9F            ///< SPI Command: Read manufacturer identification

// ============================================
// COMMUNICATION CONSTANTS, PINS AND FRECUENCY
// ============================================
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

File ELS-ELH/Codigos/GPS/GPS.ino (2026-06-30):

#include <TinyGPSPlus.h>

#define UBLOX_TX 25  ///< Transmission pin (TX) to the GPS
#define UBLOX_RX 36
#define GPS_BAUD 9600

TinyGPSPlus gps;
HardwareSerial gpsSerial(2);

struct StructUblox {
    uint32_t timestamp;   ///< Local system timestamp in ms
    
    // GPS Time
    uint8_t hour;         ///< UTC Hour
    uint8_t minute;       ///< UTC Minute
    uint8_t second;       ///< UTC Second
    
    // GPS Date
    uint16_t year;        ///< Year
    uint8_t month;        ///< Month
    uint8_t day;          ///< Day
    
    double latitude;      ///< Latitude in decimal degrees
    double longitude;     ///< Longitude in decimal degrees
    float altitude;       ///< Altitude above mean sea level in meters
    float speed;          ///< Ground speed
    float course;         ///< Course over ground
    uint8_t satellites;   ///< Number of satellites
    float hdop;           ///< Horizontal Dilution of Precision
    bool valid;           ///< GPS data validity flag
};

StructUblox ubloxData;

void InitUblox() {
    gpsSerial.begin(GPS_BAUD, SERIAL_8N1, UBLOX_RX, UBLOX_TX);

    unsigned long startTime = millis();
    bool GPSInitialized = false;
    while (gpsSerial.available() > 0) {
        gpsSerial.read();
    }
    while (millis() - startTime < 3000) {
        if (gpsSerial.available() > 0) {
            char c = gpsSerial.read(); 
            if (c == '$') { 
                GPSInitialized = true; 
                break;
            }
        }
    }
    if (!GPSInitialized) {
        Serial.println("Ublox initialization failed");
    } else {
        Serial.println("Ublox sensor initialized successfully");
    }
}

void CalibrateSensors() {
  bool GPSConected = false;
    // GPS connection check
    gpsSerial.begin(GPS_BAUD,SERIAL_8N1,UBLOX_RX,UBLOX_TX);
    while(!GPSConected){
      Serial.println("Calinrando");
      while (gpsSerial.available() > 0) {
          gps.encode(gpsSerial.read());
      }
      if (!GPSConected && gps.location.isValid() && gps.satellites.value() > 3) {
          GPSConected = true;
          Serial.println("Calibrado");
      }
    }
}
void ReadUblox() {
    // Code to read data from Ublox sensor
    ubloxData.timestamp = millis();
    while (gpsSerial.available() > 0) {
        gps.encode(gpsSerial.read());
    }
    if (gps.time.isUpdated()) {
        ubloxData.hour = gps.time.hour();
        ubloxData.minute = gps.time.minute();
        ubloxData.second = gps.time.second();
    }
    if (gps.date.isUpdated()) {
        ubloxData.year = gps.date.year();
        ubloxData.month = gps.date.month();
        ubloxData.day = gps.date.day();
    }
    if (gps.location.isUpdated()) {
        ubloxData.latitude = gps.location.lat();
        ubloxData.longitude = gps.location.lng();
    }
    if (gps.altitude.isUpdated()) {
        ubloxData.altitude = gps.altitude.meters();
    }
    if (gps.speed.isUpdated()) {
        ubloxData.speed = gps.speed.mps();
    }
    if (gps.course.isUpdated()) {
        ubloxData.course = gps.course.deg();
    }
    if (gps.satellites.isUpdated()) {
        ubloxData.satellites = gps.satellites.value();
    }
    if (gps.hdop.isUpdated()) {
        ubloxData.hdop = gps.hdop.hdop();
    }
    ubloxData.valid = gps.location.isValid();

  
  // ===== SERIAL PRINT =====

  Serial.println("===== UBLOX GPS =====");

  Serial.print("Timestamp: ");
  Serial.println(ubloxData.timestamp);

  Serial.print("Time: ");
  Serial.print(ubloxData.hour);
  Serial.print(":");
  Serial.print(ubloxData.minute);
  Serial.print(":");
  Serial.println(ubloxData.second);

  Serial.print("Date: ");
  Serial.print(ubloxData.day);
  Serial.print("/");
  Serial.print(ubloxData.month);
  Serial.print("/");
  Serial.println(ubloxData.year);

  Serial.print("Latitude: ");
  Serial.println(ubloxData.latitude, 6);

  Serial.print("Longitude: ");
  Serial.println(ubloxData.longitude, 6);

  Serial.print("Altitude: ");
  Serial.print(ubloxData.altitude);
  Serial.println(" m");

  Serial.print("Speed: ");
  Serial.print(ubloxData.speed);
  Serial.println(" m/s");

  Serial.print("Course: ");
  Serial.print(ubloxData.course);
  Serial.println(" deg");

  Serial.print("Satellites: ");
  Serial.println(ubloxData.satellites);

  Serial.print("HDOP: ");
  Serial.println(ubloxData.hdop);

  Serial.print("Valid: ");
  Serial.println(ubloxData.valid);

  Serial.println("=====================");
}

void setup() {
  // put your setup code here, to run once:
  Serial.begin(115200);
  InitUblox();


}

void loop() {
  // put your main code here, to run repeatedly:
  delay(2000);

}

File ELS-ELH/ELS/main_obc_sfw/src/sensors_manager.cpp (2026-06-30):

#include "sensors_manager.h"

#include <Arduino.h>
#include <Wire.h>
#include <SPI.h>
#include "constants.h"
#include "error_warning.h"
#include "signals.h"
#include <Adafruit_BNO055.h>
#include <Adafruit_BME280.h>
#include <MPU6050_light.h>
#include <DFRobot_QMC5883.h>
#include <Adafruit_BMP085.h>
#include <Adafruit_Sensor.h> 
#include <utility/imumaths.h>
#include <TinyGPSplus.h> 
#include <SoftwareSerial.h>
#include <Preferences.h>
#include "BluetoothSerial.h"
#include "flash_storage.h"

extern SPIClass hspi;
extern BluetoothSerial SerialBT;
extern MPU6050 mpu;
Adafruit_BMP085 bmp;
Adafruit_BNO055 bno;
Adafruit_BME280 bme(BME_CS, &hspi);
TinyGPSPlus gps;
SoftwareSerial gpsSerial(UBLOX_RX, UBLOX_TX);

StructMPU6050 mpuData;
StructQMC5883L qmcData;
StructBMP180 bmpData;
StructBNO055 bnoData;
StructBME280 bmeData;
StructUblox ubloxData;

CalibrationDataMPU mpuCalib;
CalibrationDataQMC qmcCalib;
CalibrationDataBMP bmpCalib;
CalibrationDataBNO bnoCalib;
CalibrationDataBME bmeCalib;

StructInitSensor initSensor;
StructCalibSensor calibSensor;

Preferences preferences;

bool offsetsLoaded = false;
bool offsetsSaved = false;

void initLedBuzzerActuators(){
ledcSetup(RED_CHANNEL, PWM_FREQ, PWM_RESOLUTION);
    ledcSetup(GREEN_CHANNEL, PWM_FREQ, PWM_RESOLUTION);
    ledcSetup(BLUE_CHANNEL, PWM_FREQ, PWM_RESOLUTION);
    ledcSetup(BUZZER_CHANNEL, 2000, 8); 

    ledcAttachPin(LED_RED_PIN, RED_CHANNEL);
    ledcAttachPin(LED_GREEN_PIN, GREEN_CHANNEL);
    ledcAttachPin(LED_BLUE_PIN, BLUE_CHANNEL);
    ledcAttachPin(BUZZER_PIN, BUZZER_CHANNEL);
    
    pinMode(ACTUATOR1_PIN, OUTPUT);
    pinMode(ACTUATOR2_PIN, OUTPUT);
}

void initMPU6050(){
    Wire.begin();
    byte status = mpu.begin();
    if (status != 0) {
        criticalErrorSensor("MPU6050 initialization failed");
        initSensor.initMPU = 0;
    } else {
        println("MPU6050 sensor initialized successfully");
        initSensor.initMPU = 1;
    };
}
void initQMC5883L(){
    Wire.beginTransmission(0x68); 
    Wire.write(0x37);
    Wire.write(0x02); 
    if (Wire.endTransmission() != 0) {
        criticalErrorSensor("Failed to open MPU6050 Bypass");
        initSensor.initQMC = 0;
        return;
    }

    Wire.beginTransmission(0x0D); 
    Wire.write(0x09); 
    Wire.write(0x1D); 
    Wire.endTransmission();

    Wire.beginTransmission(0x0D);
    Wire.write(0x0B);
    Wire.write(0x01); 
    
    if (Wire.endTransmission() != 0) {
        criticalErrorSensor("QMC5883L not found on 0x0D");
        initSensor.initQMC = 0;
    } else {
        println("QMC5883L initialized successfully");
        initSensor.initQMC = 1;
    }
}
void initBMP180(){
    Wire.begin();
    if (!bmp.begin()) {
	    criticalErrorSensor("BMP180 initialization failed");
        initSensor.initBMP = 0;
    } else {
        println("BMP180 sensor initialized successfully");
        initSensor.initBMP = 1;
    };
}
void initBNO055() {
    if (!bno.begin()) {
        criticalErrorSensor("BNO055 initialization failed");
        initSensor.initBNO = 0;
    } else {
        println("BNO055 sensor initialized successfully");
        initSensor.initBNO = 1;
    };
}
void initBME280() {
    if (!bme.begin()) {
        criticalErrorSensor("BME280 initialization failed");
        initSensor.initBME = 0;
    } else {
        println("BME280 sensor initialized successfully");
        initSensor.initBME = 1;
    }
}
void initUblox() {
    gpsSerial.begin(GPS_BAUD);

    unsigned long startTime = millis();
    bool GPSInitialized = false;
    while (gpsSerial.available() > 0) {
        gpsSerial.read();
    }
    while (millis() - startTime < 3000) {
        if (gpsSerial.available() > 0) {
            char c = gpsSerial.read(); 
            if (c == '$') { 
                GPSInitialized = true; 
                break;
            }
        }
    }
    if (!GPSInitialized) {
        criticalErrorSensor("Ublox initialization failed");
        initSensor.initGPS = 0;
    } else {
        println("Ublox sensor initialized successfully");
        initSensor.initGPS = 1;
    }
}

bool loadOffsets() {
  preferences.begin(NVS_NAMESPACE, true);

  uint8_t version = preferences.getUChar(VERSION_KEY, 0);
  if (version != OFFSETS_VERSION) {
    criticalErrorSensor("Offset version mismatch, discarding data...");
    preferences.end();
    return false;
  }

  size_t offsetsLen = preferences.getBytesLength(OFFSETS_KEY);
  size_t calLen     = preferences.getBytesLength(CAL_LEVELS_KEY);

  if (offsetsLen != sizeof(adafruit_bno055_offsets_t) ||
      calLen     != sizeof(CalibrationDataBNO)) {
    criticalErrorSensor("Incomplete or corrupted data in NVS");
    preferences.end();
    return false;
  }

  adafruit_bno055_offsets_t offsets;

  preferences.getBytes(OFFSETS_KEY, &offsets, sizeof(offsets));
  preferences.getBytes(CAL_LEVELS_KEY, &bnoCalib, sizeof(bnoCalib));
  preferences.end();
  
  Serial.println("Offsets encontrados en NVS:");
  Serial.print("  SYS: ");  Serial.print(bnoCalib.bnoSystemStatus);
  Serial.print("  GYR: ");  Serial.print(bnoCalib.bnoGyroStatus);
  Serial.print("  ACC: ");  Serial.print(bnoCalib.bnoAccStatus);
  Serial.print("  MAG: ");  Serial.println(bnoCalib.bnoMagStatus);

  bno.setMode(OPERATION_MODE_CONFIG);
  delay(25);

  bno.setSensorOffsets(offsets);
  delay(25);

  bno.setMode(OPERATION_MODE_NDOF);
  delay(600);

  println("Offsets cargados desde NVS y aplicados");
  return true;
}

void saveOffsets() {
  adafruit_bno055_offsets_t offsets;

  bno.setMode(OPERATION_MODE_CONFIG);
  delay(25);

  bno.getSensorOffsets(offsets);

  bno.getCalibration(
    &bnoCalib.bnoSystemStatus,
    &bnoCalib.bnoGyroStatus,
    &bnoCalib.bnoAccStatus,
    &bnoCalib.bnoMagStatus
  );

  preferences.begin(NVS_NAMESPACE, false);
  preferences.putUChar(VERSION_KEY, OFFSETS_VERSION);
  preferences.putBytes(OFFSETS_KEY, &offsets, sizeof(offsets));
  preferences.putBytes(CAL_LEVELS_KEY, &bnoCalib, sizeof(bnoCalib));
  preferences.end();

  Serial.println("Offsets guardados en NVS:");
  Serial.print("  SYS: "); Serial.print(bnoCalib.bnoSystemStatus);
  Serial.print("  GYR: "); Serial.print(bnoCalib.bnoGyroStatus);
  Serial.print("  ACC: "); Serial.print(bnoCalib.bnoAccStatus);
  Serial.print("  MAG: "); Serial.println(bnoCalib.bnoMagStatus);

  bno.setMode(OPERATION_MODE_NDOF);
  delay(100);
}
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

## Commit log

2026-02-25 Add ELH-ELS architecture and design docs
    Add initial ELH-ELS documentation covering system goals, architectures, and design decisions. Files added:
    - ELS-ELH/Architecture Proposal.md: Battery-pack concept, common subsystems (GPS, dual IMUs, barometer, flash/SD, LED/buzzer) and three architecture options (PMC + dual OBC, dual OBC without PMC, single OBC).
    - ELS-ELH/Decision Tracking.md: Selected Architecture #1 (PMC + dual OBC) as baseline and rationale; component selection notes for load switches (eFuse), power monitor ICs (INA family), ideal-diode pack switchover, and other power subsystem tradeoffs.
    - ELS-ELH/Objectives and Requirements.md: Project objectives, success criteria, system req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
2026-02-25 Add IREC 2025 files for processing
    Include all the data gathered from IREC 2025 for a post processing
    [162_Universidad de Antioquia_cubesat_DATA.csv, BLRV.csv, BR_deploy_settings__06-12-2025_16_30_38.xlsx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]
2026-03-27 Add electrical connections and safety equipment documentation
    Add electrical connections and safety equipment documentation, preliminary pin budget and safety architecture for OBCs and detailed abbreviation table for electrical components.
2026-04-21 dev/PCB and shematics update (#13)
    * Preliminary schematics and footprints of components
    * some progress
    * Some progress
    * Preliminary final schematics
    All that's left is to add capacitors and make any other necessary changes.
    * Finished schematics
    * Pin change
    * Delete sensors.kicad_sch
    * Modification of the IMU Fused schematic
    * Advances
    Components almost ready, only 3 screw terminal footprints and component placement are needed
    * Components preliminar distribution
    * Editing some footprints and connections
    * Update folder structure and PCB A advanced
    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
    [KiCad_ELH.kicad_pcb, KiCad_ELH.kicad_sch, PCB_A.kicad_pcb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]
2026-05-02 General Update
    Final version & manufacture files of both PCBs + codes of unit testing on modules and functionalities
    * Update on net labels of both PCBs
    * Update in symbols and footprints
    * Unitary Tests Codes
    * Update on schematics B
    * Update in PCB B - new layout
    * Update in schematic A
    * PCB B Almost finishhed
    * PCB B ready, PCB A layout ready
    * Finish PCB B
    * Solve DRC problems with B
    * PCB A routed
    * reorganized resistances
    * regulator's names changed
    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
    [PCB_A-B_Cu.gbr, PCB_A-B_Mask.gbr, PCB_A-B_Paste.gbr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]
2026-05-17 Documentation (#15)
    * Changes
    * More changes
    * changes
    * changes
    * more
    * test
    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
2026-06-17 Add CTR OBC PlatformIO ESP32 project
    Introduce a new PlatformIO-based ESP32 project for the CTR on-board computer (CTR/ctr). Adds project config (platformio.ini), editor recommendations, and .gitignore. Implements core headers and sourc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
2026-06-30 Improve motor control and flash SPI handling
    Multiple updates across CTR and unit tests:
    - CTR/ctr/src/global.cpp: Increased RW controller derivative gain (kd 0.1 -> 70.0).
    - CTR/ctr/src/rtos_tasks.cpp: Enabled control flags by default (enterCtr, enableCtr = true); added currentPWM and replaced instant setMotorPWM with a ramping implementation to smoothly change PWM; restored previous setMotorPWM as commented code; added debug Serial prints in getDataTask and btHandlingTask.
    - ELS-ELH/ELS/Unitary_tests/MOSFETS_ESP: minor whitespace added.
    - ELS-ELH/ELS/Unitary_tests/TEST_FLASH_BME:
    - TEST_FLASH_BME.ino: increased read buffer size, added PIN_CS_LORA init, reorganized setup formatting, en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
    [MOSFETS_ESP.ino, TEST_FLASH_BME.ino, flash_storage.cpp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]
